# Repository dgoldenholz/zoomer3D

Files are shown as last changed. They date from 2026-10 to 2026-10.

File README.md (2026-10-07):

# Zoomer XTI-30

An articulated Blender robot based on `zoomer.png`, with a MuJoCo motor model, URDF, and print prototypes for a Prusa XL with five tools. The neutral model is 180 mm tall and 100 mm wide. The head, chest instruments, ribbed cylinder, tread base, and four-finger hands follow the drawing.

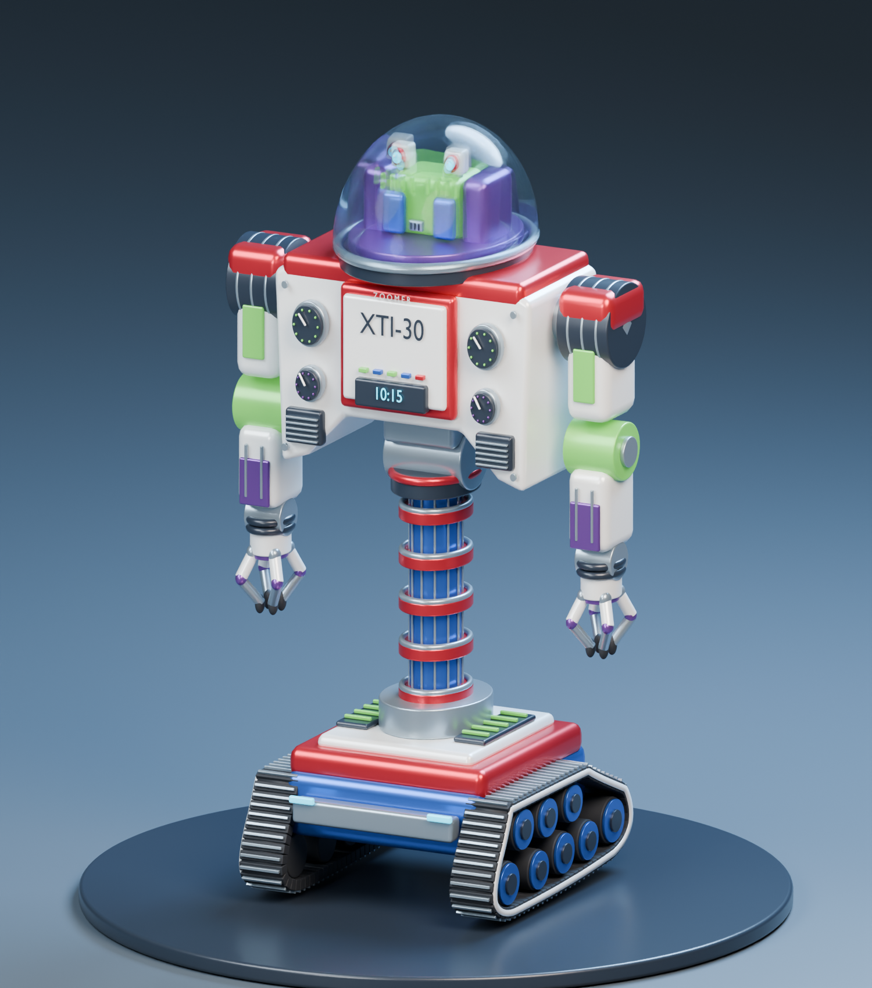
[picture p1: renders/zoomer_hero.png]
Zoomer


The revised tread layout is shown in the [side elevation](renders/zoomer_treads_side.png). The steep end is the front; the long upper slope faces rearward.

## Revised modular print

For the physical model, use [the modular print revision](print/modular/PRINTING.md). It follows the drawing's wider proportions at 180 mm tall, uses 12 printed parts and keeps only head and shoulder movement. All hardware is printed plastic. The main parts lie flat for printing; the clear dome has its own supported print.

Start with [the fit coupons](print/modular/plates/XL_fit_coupons.3mf), then choose [single-material](print/modular/plates/XL_main_single_material.3mf) or [five-color](print/modular/plates/XL_main_five_color.3mf). See the [drawing comparison](print/modular/qa/drawing_comparison.png) and [Blender inspection model](assets/zoomer_modular.blend). The files under `print/articulated/` are the earlier captive-joint prototype.

The user subsequently printed the modular robot and reported good fits, but insufficient dome clarity. The [three-piece vase dome](print/vase_dome/PRINTING.md) replaces that cover with a continuous thin shell, separate cap and mounting ring. Its two PrusaSlicer projects use 0.25 mm layers; only the shell uses vase mode. Open the [revised inspection scene](assets/zoomer_vase_dome.blend) to examine it.

The curved vase dome improved transparency in the user's print, but distorted the image. The next [flat viewing covers](print/flat_window_domes/PRINTING.md) include a flat-wall test, a faceted vase shell and a normal-printed hood that holds a 0.50 mm clear PETG sheet window. Four sliced XL projects, a full-size cutting template and both Blender inspection models are included. These new variants have not yet been physically printed.

## Drawing and training

The retrained robot completes the 19-stroke "ai is so cool" drawing with 0.36 mm RMS tracking error and returns all four markers. Open [the video player](app/video.html) or [the MP4](renders/zoomer_ai_is_so_cool.mp4). The final frame compares the target with measured ink. See [training details](simulation/TRAINING.md) for the evaluated run and simulation assumptions.

Open the local drawing studio with `.venv/bin/python app/server.py`, then visit <http://127.0.0.1:8765>. It records four-color drawings and launches curriculum training for marker collection, drawing and color changes. The default position tolerance is 3 cm RMS.

See [the workshop guide](simulation/TRAINING.md) for the simulator, learned policy, visibility checks, error calculation and commands. The [integrated articulation design](print/articulated/PRINTING.md) is separate from the original static print.

The saved PPO policy completed the four-color example in 399.42 simulated seconds, with 1.57 cm RMS error and all markers returned. This is a small controller-assisted learning test. See the workshop guide for its scope and physics assumptions.

The earlier captive mechanism is preserved in `assets/zoomer_print_in_place.blend` and `print/articulated/`. Use the modular revision above for the revised physical model.

## Open the model

Open [`assets/zoomer.blend`](assets/zoomer.blend) in Blender 4.5 or later. Frame 1 is the neutral pose. Play frames 1 to 250 for the articulation demonstration.

The `01 | Joint controls (degrees)` collection contains the joint hierarchy. Select a joint and edit its `command_deg` custom property. Clear that property's keyframes before posing it manually. Each axis has its own pivot and limit. Geometry moves as rigid parts, with no skin deformation. The dome and head rotate together through a continuous yaw joint.

The drawing is packed into the Blender file in the hidden reference collection. The studio floor, plinth, lights, and cameras are separate from the robot.

## Articulation

| Assembly | Motor channels | Motion |
| --- | ---: | --- |
| Waist | 2 | Continuous yaw; pitch ±25° |
| Head and dome | 1 | Continuous yaw |
| Each arm | 7 | Three shoulder axes, elbow flexion, forearm rotation, two wrist axes |
| Each hand | 8 | Four fingers with two hinges each |
| Base | 2 | Independent left and right drive motors |
| Total | 35 | Plus fourteen passive wheel axles |

The exact axes, ranges, torque assumptions, and ordering are in [`simulation/motor_map.json`](simulation/motor_map.json). Coordinates use metres, +X to the robot's left, -Y forward, and +Z up. The Python design file uses construction coordinates and an explicit `scale_xyz` conversion; the exported Blender, MJCF, and URDF files use metres.

## Run the simulation

```sh
python3 -m venv .venv
.venv/bin/pip install -r requirements.txt
.venv/bin/python simulation/demo.py
```

The demo follows a 10 mm circular tool path in front of a miniature whiteboard. It computes a joint target with inverse kinematics, then applies normalized torque commands at every physics step. It sets the initial joint pose once. The recorded trajectory thereafter comes from MuJoCo dynamics.

On macOS, run the interactive viewer through MuJoCo's launcher:

```sh
.venv/bin/mjpython simulation/demo.py --viewer
```

The three scenes are:

| File | Purpose |
| --- | --- |
| `simulation/zoomer.xml` | Floating base, ground contact, drive motors and arms |
| `simulation/zoomer_fixed.xml` | Fixed base for articulation and controller tests |
| `simulation/whiteboard.xml` | Fixed base, board and an attached marker representation |

[`simulation/control.py`](simulation/control.py) supplies `ZoomerEnv`. `step(action)` accepts 35 normalized torque commands in [-1, 1] and advances 10 ms. Observations include joint positions, velocities, the tool position, and a target position. The reward penalizes target distance and control effort. A tool position within 1 mm counts as success. `command(**named_torques)` provides a named interface. `simulation/zoomer.urdf` and its adjacent `meshes/` directory provide the same visual geometry and joint tree for other robotics tools.

## What the simulation establishes

The validation script loads all three scenes, runs two seconds of dynamics in each, tests all 35 motors individually, compares URDF axes and limits, and checks the circular tool trajectory. Run it with:

```sh
.venv/bin/python scripts/validate_simulation.py
```

Results are saved in [`simulation/validation.json`](simulation/validation.json). The tool trace is in [`renders/whiteboard_trace.svg`](renders/whiteboard_trace.svg), with time samples in the adjacent JSON file.

These three original scenes are controller examples. The separate workshop scene and PPO curriculum are described in `simulation/TRAINING.md`. The circle is a controller demonstration, and there is no physical ink deposition or marker-force model. The marker is attached to the palm rather than grasped as a free object. The environment is a NumPy interface, not a Gymnasium adapter. Outcome descriptions currently need numeric target positions; there is no language-to-task planner.

Masses, inertias, damping, and torque limits are design assumptions, with a total model mass of about 770 g. They are not measurements or hardware specifications. Each track follows the supplied side view: five lower wheels and three upper return rollers inside an asymmetric belt, with a steep front and a sloped rear. Wheel-contact cylinders approximate the belt contact; the first four lower contacts share the ground plane, and the rear wheel sits higher. The visible wheels have blue rims and dark hubs, with an ivory outline around the belt. The fixed-base scenes leave 2 mm beneath the tread contact cylinders so the drive motors can rotate on the bench. The belt does not circulate or deform. Robot self-collision is disabled in the starter scenes; contact with the floor and external objects is enabled. URDF uses cylinders where MJCF uses capsules. Joint sweeps can intersect the cosmetic shells, and a hardware design will need collision-aware motion limits, bearing clearances, motor mounts, wiring paths, and load checks.

## 3D printing

Start with [`print/modular/PRINTING.md`](print/modular/PRINTING.md). The older [`print/PRINTING.md`](print/PRINTING.md) describes the first prototypes. The package contains a fused static display body, a separate dome, five captive-hinge clearance variants, and a captive ball-joint prototype. The newer integrated mechanical design is in `print/articulated/`. Its captive bearings, wheels and linked treads are separate from these first prototypes.

No G-code is supplied. The older captive-joint prototypes have not been physically tested. Use their test parts to establish the printer's clearances before printing the integrated assembly.

## Rebuild

The project was generated with Blender 4.5.3 LTS and validated with MuJoCo 3.14.0. Set `BLENDER` to your Blender executable, then run. On this Mac the executable is `/Users/dgoldenh/Applications/Blender.app/Contents/MacOS/Blender`.

Blender is now 4.5.14 LTS. The modular model passed load, joint-control and render checks after the update. Automated launches on this Mac require the approved execution path outside the restricted sandbox because graphics-device detection crashed there. See the [maintenance record](diagnostics/blender/README.md) and `AGENTS.md` before rebuilding.

```sh
"$BLENDER" --background --python scripts/build_blender.py -- --render
.venv/bin/python scripts/export_simulation.py
.venv/bin/python scripts/validate_simulation.py
.venv/bin/python scripts/build_print.py
"$BLENDER" --background --python scripts/export_print_blender.py
.venv/bin/python scripts/export_display_print.py
```

The model, meshes, renders, and print files are generated artifacts. Edit `scripts/robot_design.py` to change the robot's dimensions or joint tree, then rebuild. The source drawing remains unchanged.

References used for the exports and workflow: [MuJoCo XML reference](https://mujoco.readthedocs.io/en/latest/XMLreference.html), [MuJoCo Python viewer](https://mujoco.readthedocs.io/en/stable/python.html), and [Prusa's modeling guidance](https://help.prusa3d.com/article/modeling-with-3d-printing-in-mind_164135).

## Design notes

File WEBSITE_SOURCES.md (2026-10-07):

# Zoomer3D sources

The four notebook scans and two finished-print photographs were supplied by the owner. The owner clarified that the body in the finished-print photographs is metallic silver. The owner states that the drawings were made in 1991 at age 13, and that GPT-6 Astra was used to develop the printable model and generate the printer files. On October 5, 2026, the owner confirmed that the cover shown in the photographs is the faceted printed PETG cover.

Body dimensions, joints, orientations, assembly steps and baseline settings come from `print/modular/PRINTING.md` and the embedded configurations in the XL projects. The five-color v2 project's settings differ from the baseline and are identified separately on the site.

The dome history comes from `README.md`, `print/vase_dome/PRINTING.md`, and `print/flat_window_domes/PRINTING.md`. Older notes about the faceted cover being unprinted are superseded by the owner's new photographs and confirmation. The sheet-window alternative is described as another option without a claim that it was printed.

The owner supplied `IMG_3064.JPEG` to illustrate several attempts at a more transparent head cover. It is included unchanged as `docs/assets/head-cover-attempts.jpg`.

The head-cover section uses the existing faceted-cover 3D render to identify the final design. Its numbered history ends at the faceted cover; the sheet-window design is a separate optional alternative.

The site is a static exhibit with local image and download assets. It contains no credentials or analytics. Original repository files and source photographs are preserved.

## Assembly and drawing additions

The exploded robot, cap underside and adapter views were rendered from the existing faceted-cover Blender scene on CPU. The original model files were not saved or changed. Existing cover and articulated-robot renders come from the repository.

Training metrics and programmed-versus-learned descriptions were checked against `simulation/TRAINING.md`, `training/zoomer_readable/status.json` and the recorded run metadata. The website drawing editor preserves the existing target schema and exports JSON for the local MuJoCo app. Training runs locally, not in the hosted page. The packaged MP4 is the existing 202.12-second recorded run.

The six-frame collage contains direct JPEG extractions from that packaged MP4. Captions use video playback times, not simulation time. Exact frame times and the source path are saved in `docs/assets/drawing-stills/frames.json`.

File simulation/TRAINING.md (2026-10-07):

# Drawing workshop

The workshop uses the 180 mm robot, a 480 × 200 mm whiteboard and a side table with black, red, blue and green markers. The editor maps drawings to a reachable 300 × 60 mm strip on the board. Each marker is a separate physical body.

## Open the drawing studio

From the repository root:

```sh
.venv/bin/python app/server.py
```

Open <http://127.0.0.1:8765>. Draw with a mouse, pen or touch. The editor has four colors, one 1.5 mm marker size, undo, stroke replay and JSON import/export. It saves stroke order, point order and relative timestamps. It never groups strokes by color. Black, red, black means three collection visits in that order.

Save the target, choose a training budget and select **Train this drawing**. One job runs at a time. **Stop and save checkpoint** requests a clean stop. Files stay on this computer in `targets/` and `training/<run-id>/`.

## Error and speed

The default distance tolerance is 3 cm RMS. For ordered 3D target positions `p` and measured nib positions `q`, the calculation is:

```text
MSE = mean(sum((p - q)², over x, y, z))
RMS distance = sqrt(MSE)
3 cm RMS = 0.03 m RMS = 0.0009 m² MSE
```

The UI accepts 0.05 to 10 cm. It shows both distance and MSE. The selected value is an overall error ceiling. Lettering also needs a local tracing tolerance, capped at 0.75 mm. The controller samples the path at intervals no larger than 0.6 mm and advances only after a visible, physical nib contact reaches the next point. This prevents the 3 cm default from skipping whole letters.

The reward subtracts elapsed time and control effort, and penalizes tracking errors beyond the local tolerance. Terminal evaluation also requires at least 98% of target samples to have ink within 1 mm and at least 95% of ink samples to lie within 1 mm of their assigned stroke. Missing strokes cannot earn a good score just because the completed contacts had low RMS error.

## Run or train from the terminal

```sh
# Controller baseline, with a task trace.
.venv/bin/python simulation/run_workshop.py --drawing targets/four_colors.json

# Interactive MuJoCo view on macOS.
.venv/bin/mjpython simulation/run_workshop.py --viewer

# Train the curriculum, then evaluate each stage on a separate reset seed.
.venv/bin/python simulation/train.py --drawing targets/four_colors.json --steps 100000 --output training/my_run

# Continue from a checkpoint.
.venv/bin/python simulation/train.py --drawing targets/four_colors.json --resume training/my_run/checkpoint.zip --steps 100000 --output training/continued

# Evaluate the saved policy.
.venv/bin/python simulation/run_workshop.py --policy training/my_run/policy.zip --output training/policy_trace.json
```

Stages are driving, pickup, drawing and the complete sequence. Skill resets sample different strokes and colors. A stage must pass evaluation before the next stage begins. The status file records the stage, number of training steps, measured results and whether the full sequence passed. A saved policy file alone does not mean training succeeded.

PPO learns seven residual commands around a task controller: two wheel-speed corrections, three Cartesian hand corrections, a grip correction and a head-yaw correction. Inverse kinematics and torque feedback turn those commands into the robot's 35 motor commands. This assistance shortens training. It is not learning all 35 joint torques from scratch. The zero-residual baseline is available for comparison.

The task controller preserves the drawing sequence. It carries one marker at a time, returns it to its original holder before a color change and returns the last marker when the drawing is finished. The base centers under each letter and plans an 85 mm gap to the board. Standing closer forced the wrist toward its limit and caused contact loss. For long strokes, the controller lifts the nib before repositioning along the board, then resumes the same point. Wheel residuals apply only during travel. At a station, wheel-angle feedback holds the base in place. After lifting the nib, the robot backs away with the arm held still before folding it for travel. Pickup and return can try alternate inverse-kinematics poses; writing keeps the arm configuration continuous. The ink trace records contact breaks rather than drawing a line through a pen-up move.

## Sight, contact and measurements

Both eyes have a 120° vertical field of view, with fixed optics angled 25° down. The head supplies yaw. MuJoCo rays test the field of view and occlusion by the scene and robot collision shapes. The transparent dome does not block those rays. Marker poses in the policy observation are zeroed when no sampled part of the marker is visible.

Grasping, lifting and placement require marker visibility. Drawing requires a visible patch within 3 mm of the target because the nib can cover its own contact point. An occluding wall still blocks that patch. The visibility test uses geometric object detection, not a trained RGB vision model. The task controller knows the fixed station layout. Eye cameras are present in the MJCF for future camera-based perception work.

A pickup must bring the gripper within 4 mm of the marker grip point and establish contact from at least two fingers. A weld then approximates a secure grasp. Finger-to-marker contacts are disabled while that weld holds the marker, avoiding two competing constraints. The marker can still contact the board and table. The holders use releasable docking constraints. No robot or marker pose is teleported during a task step. Curriculum resets can start near a station or with a marker already held.

Ink appears only when the nib contacts the board. Its position comes from the spherical nib's forward contact surface. A 1 kHz Cartesian feedback loop tracks the nib while torque control holds the arm pose. A slower pressure adjustment varies the normal preload between 4 and 60 mN. The nib-to-board friction coefficient is 0.2 and the grasp weld time constant is 2 ms; both are simulation assumptions. The trace retains the measured nib position, time, color, stroke index, contact flag and visibility flag. The RMS calculation includes contact samples while following the target, including samples outside the tolerance. Coverage records ordered target completion separately from error.

The drive model uses two effective traction contacts and low-friction support rollers. It is a differential-drive approximation to the treads. The decorative belt does not deform in MuJoCo. Robot self-collision remains disabled in the starter physics. Masses, inertias and torque limits are estimates. These choices support task development, but they are not a validated physical robot model.

## Validation and rebuilding

```sh
.venv/bin/python scripts/build_workshop.py
.venv/bin/python -m pytest -q tests/test_workshop.py
```

The tests cover drawing order and units, invalid inputs, eye occlusion, contact-qualified pickup, real board contact, stroke completion and invalid motor commands. `training/full_sequence.json` records the baseline's full sequence. Training results are stored separately from controller demonstrations.

The original checkpoint in `training/verified_policy/` belongs to the earlier four-mark controller. The longer target in `training/fbef1730519e4f848773550c1c03f80b/` failed during red-marker pickup and produced poorly matched lettering. Those checkpoints remain as historical artifacts. The revised controller changes the observation shape and requires a fresh policy relative to those original checkpoints. Use `--stages drawing sequence` to fine-tune these skills without repeating the pickup curriculum.

## Verified text drawing

`training/zoomer_readable/policy.zip` completes the saved 19-stroke target `targets/3201207f878b4707ab8753bffb68dbac.json`. The recorded evaluation uses seed 300 with randomized initial placement and traction. It completed all 19 strokes and returned black, red, blue and green markers in 814.74 simulated seconds.

The measured RMS tracking error was 0.361 mm, with a maximum sampled error of 0.589 mm. Every target sample had ink within 1 mm, and every ink sample was within 1 mm of its assigned stroke. The planar target-to-ink RMS distance was 0.248 mm. These figures describe this recorded run, not a benchmark on unseen drawings or hardware.

The policy accumulated 21,326 environment steps across controller revisions, including 1,024 after the canvas-to-board mapping correction. Controller changes supply most of the new capability: finer waypoint tracking, reachable drawing stances, marker-return pose recovery and contact feedback. This experiment does not isolate PPO's contribution to accuracy or speed.

The board faces +Y. Canvas-right therefore maps to world -X; canvas-up maps to +Z. Recordings retain this drawing frame alongside the target and policy hashes. The source snapshot is in `training/zoomer_readable/source/`.

Watch `renders/zoomer_ai_is_so_cool.mp4` or open `app/video.html`. Travel plays at 12x, drawing at 0.5x, and ordinary marker handling at real time. The ending compares the target with recorded contact ink. The video includes actual MuJoCo poses and does not animate the robot along the target curve.

To repeat the recorded reset with the saved policy:

```sh
.venv/bin/python scripts/record_workshop_video.py capture --drawing targets/3201207f878b4707ab8753bffb68dbac.json --policy training/zoomer_readable/policy.zip --randomize --seed 300 --output-prefix renders/repeated_text
.venv/bin/python scripts/record_workshop_video.py preview --output-prefix renders/repeated_text
.venv/bin/python scripts/record_workshop_video.py render --output-prefix renders/repeated_text
```

The implementation follows the [MuJoCo ray API](https://mujoco.readthedocs.io/en/stable/APIreference/APIfunctions.html#mj-ray), [MuJoCo weld constraints](https://mujoco.readthedocs.io/en/stable/XMLreference.html#equality-weld) and [Stable-Baselines3 PPO interface](https://stable-baselines3.readthedocs.io/en/master/modules/ppo.html).

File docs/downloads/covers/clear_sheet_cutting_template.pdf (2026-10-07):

# Zoomer clear-sheet window

## Full-size cutting template | 0.50 mm clear PETG sheet

Print at 100% or Actual size. Turn off Fit, Shrink and Scale to fit. Measure the 50 mm box below before cutting the sheet.

## Cut on the black outline

25.20 mm

37.88 mm

26.60 mm

## Narrow edge at the top

Keep the sheet flat.
Do not print this panel in filament. Leave protective film on while cutting.

Try the fit before applying adhesive. The rebate allows 0.20 mm per edge. Trim burrs rather than forcing the fit.

## Scale check

50.00 x 10.00 mm

Measure between the line centers.
If the size is wrong, correct printer scaling.

## Optional target for the flat-wall test

Place the target inside the test tube and view it through one wall only. Compare it with the uncovered target at the same distance.

# XTI-30

The tube is an optical test, not a mounting part. A flat printed wall can still show layer ripples. The sheet version removes those printed ridges.

Use with 04_XL_sheet_hood_and_retainer_NORMAL.3mf and the shared cap/adapter.
Geometry checked; this revision has not been physically printed. | 2026-10-02

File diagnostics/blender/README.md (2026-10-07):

# Blender maintenance, September 28, 2026

Blender was updated from 4.5.3 to 4.5.14 LTS, within the same release series. The active application remains at `/Users/dgoldenh/Applications/Blender.app`. The previous version is available at `/Users/dgoldenh/Applications/Blender 4.5.3 backup.app`.

The installer came from [Blender's official mirror](https://mirror.blender.org/release/Blender4.5/blender-4.5.14-macos-arm64.dmg). Its SHA-256 matched the [published checksum](https://mirror.blender.org/release/Blender4.5/blender-4.5.14.sha256). The application passed the macOS signature check and was accepted as a notarized release from Stichting Blender Foundation.

## Crash diagnosis

The crash recorded at 17:34 on September 28 occurred in `supports_barycentric_whitelist` and `MTLBackend::metal_is_supported` during Blender startup. The report had no Python backtrace. Blender had not loaded the Zoomer model or run its build script.

That launch ran inside the restricted automation environment. Subsequent launches of the same 4.5.3 binary completed outside it. This points to restricted access during graphics-device detection. It does not establish that the update alone fixes the crash.

Future automated Blender jobs use the approved execution path outside that restriction, with factory startup settings and CPU rendering. The repository's `AGENTS.md` records this requirement. Normal desktop launches continue to use the user's preferences. No macOS security settings were changed.

## Verification

The updated application launched normally on the desktop and displayed the modular model in its camera view. A separate background check opened `assets/zoomer_modular.blend`, evaluated all three joint controls at 15 degrees, restored their neutral positions and rendered the model with Cycles on CPU.

- Blender reported version 4.5.14 LTS.
- The model contained 34 mesh objects and the expected head and shoulder controls.
- The 640 by 800 pixel render completed and Blender exited with status zero.
- The saved model's SHA-256 was unchanged after the check.

The [check results](update_check.json), [render log](update_check.log) and [test image](update_render.png) record the run. This verifies startup, model loading, controls and rendering in the tested configuration. It is not a claim that Blender cannot crash under other workloads.

To roll back, quit Blender and exchange the active and backup application names in Finder. Keep the current version under another name so both remain available. The model files do not need conversion.

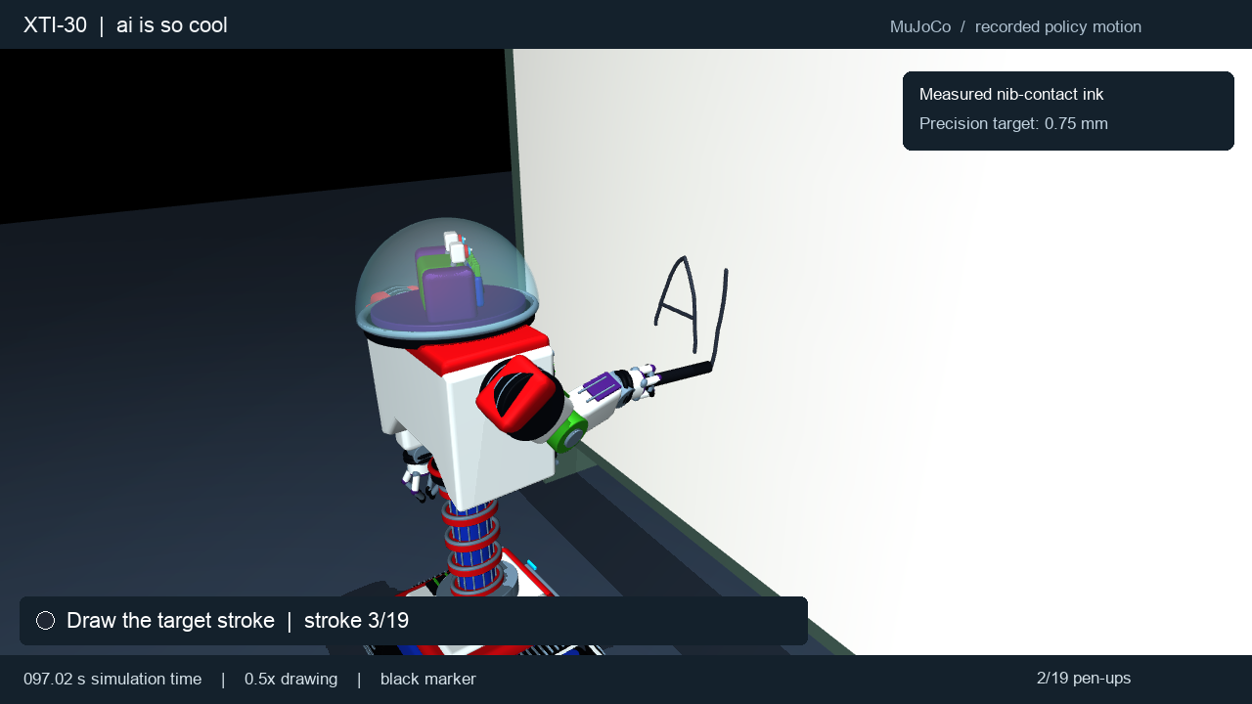
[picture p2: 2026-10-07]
docs/assets/drawing-video-poster.png

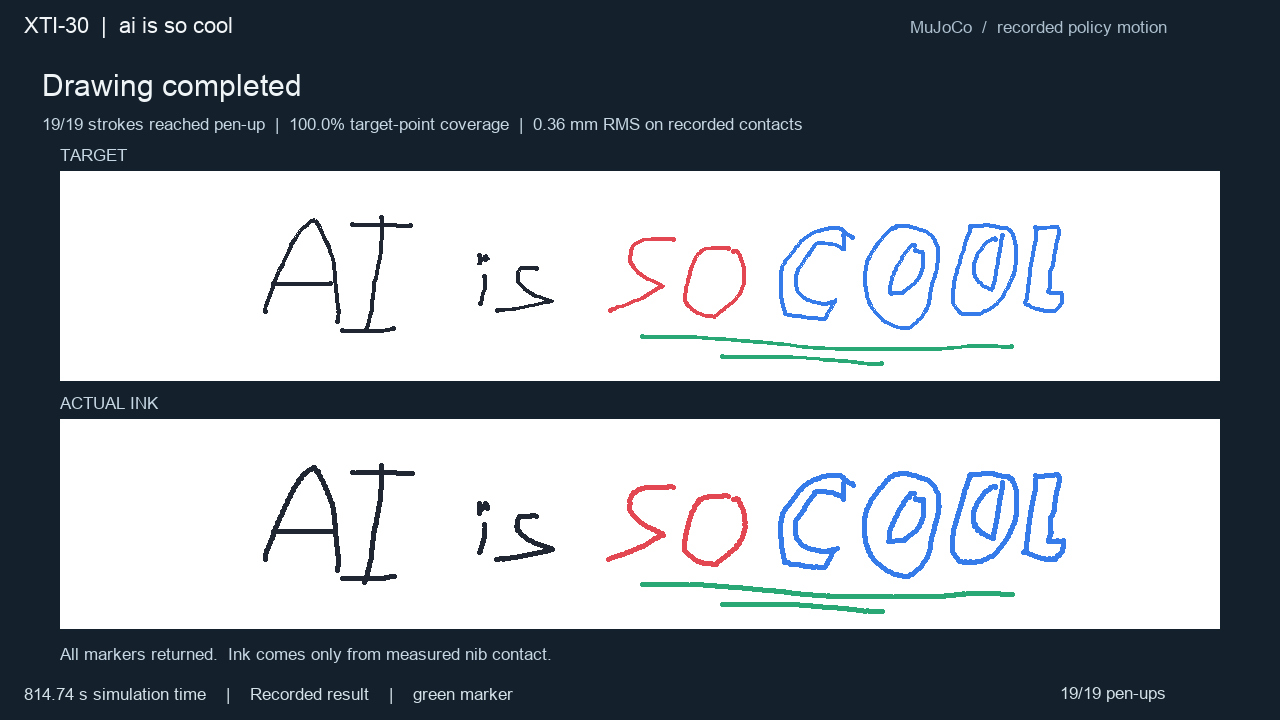
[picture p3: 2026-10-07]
renders/zoomer_ai_is_so_cool_poster.png

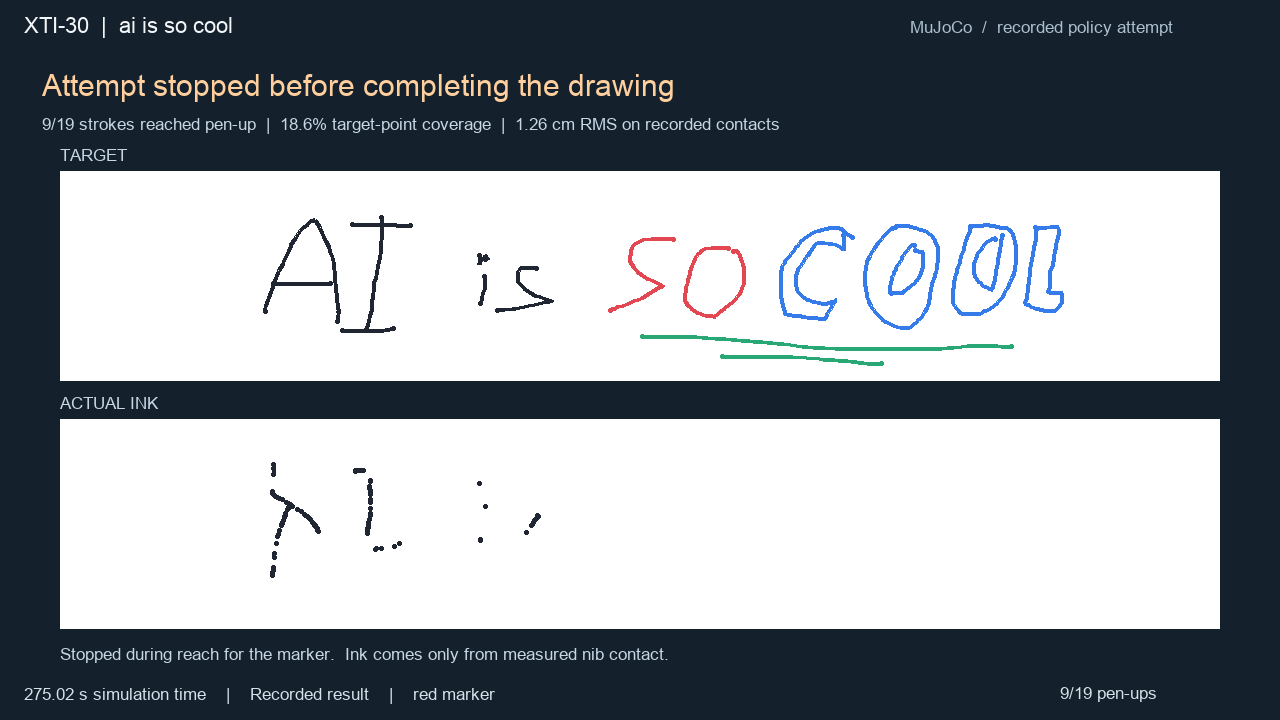
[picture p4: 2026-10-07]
renders/ai_is_so_cool_poster.png

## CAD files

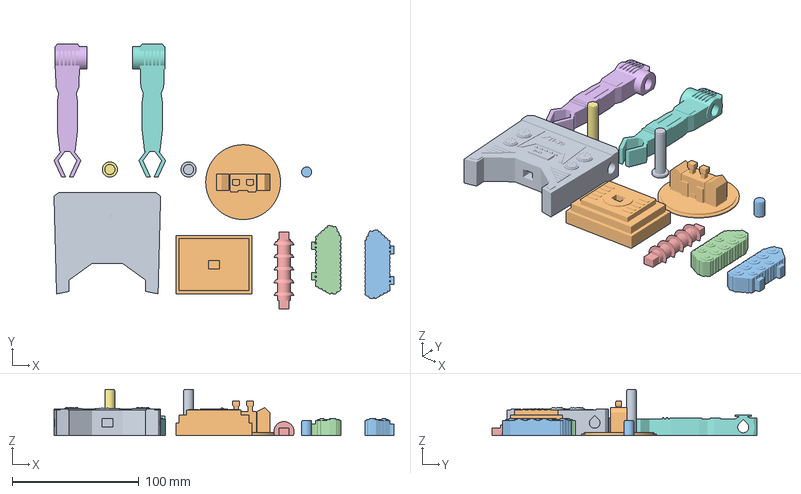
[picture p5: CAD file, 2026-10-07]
docs/downloads/body/XL_main_five_color-v2.3mf
267.8 x 209.0 x 36.3 mm
torso
base_deck
right_track
left_track
waist_column
right_arm
right_shoulder_pin
left_arm
left_shoulder_pin
head
head_peg

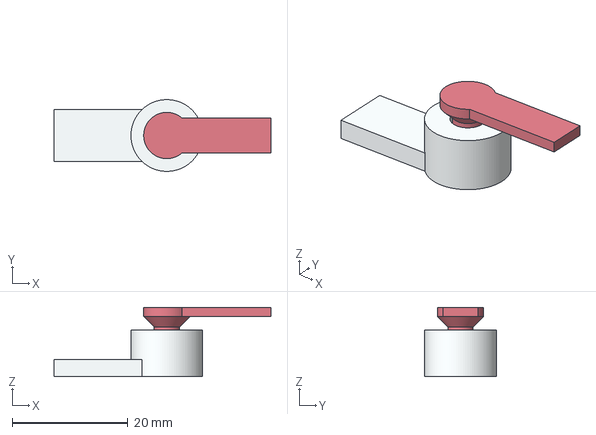
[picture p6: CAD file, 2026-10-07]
print/hinge_35_assembled.3mf
37.5 x 12.4 x 12.0 mm

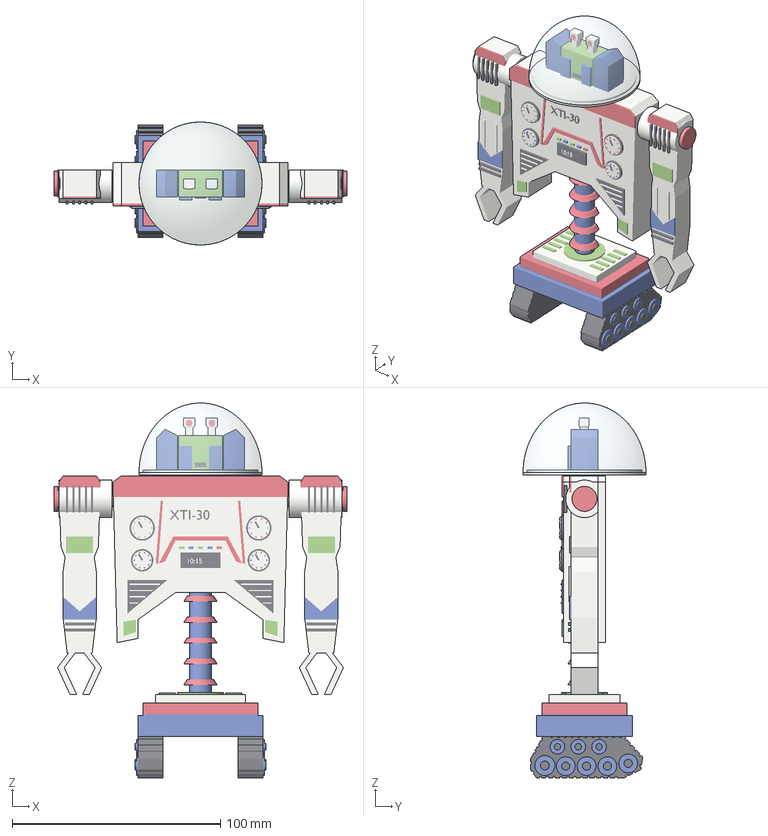
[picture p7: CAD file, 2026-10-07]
print/modular/assembly_view_only.3mf
140.6 x 59.0 x 180.0 mm
torso
base_deck
right_track
left_track
waist_column
right_arm
right_shoulder_pin
left_arm
left_shoulder_pin
head
head_peg
dome

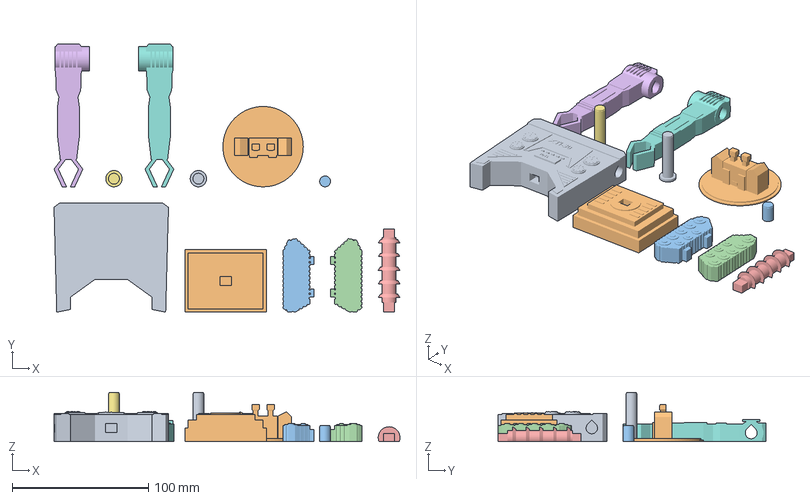
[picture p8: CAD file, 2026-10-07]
docs/downloads/body/XL_main_single_material.3mf
254.0 x 197.0 x 36.3 mm
torso
base_deck
right_track
left_track
waist_column
right_arm
right_shoulder_pin
left_arm
left_shoulder_pin
head
head_peg

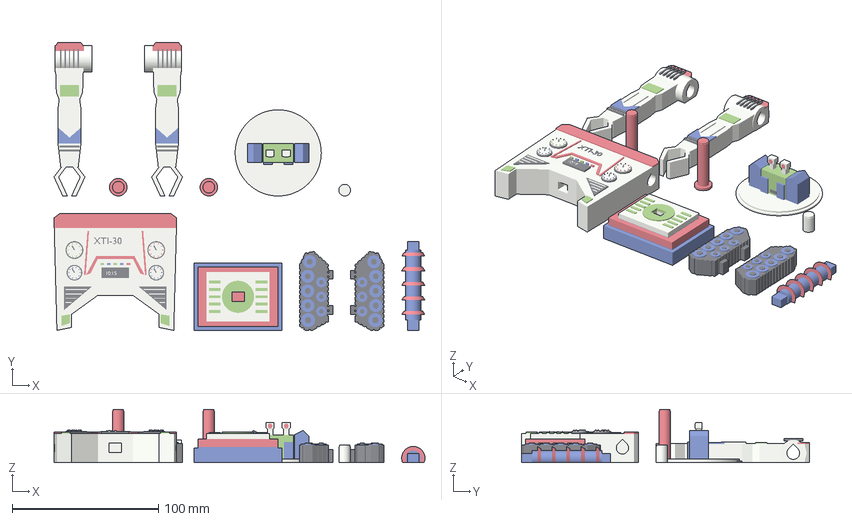
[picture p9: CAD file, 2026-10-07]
print/modular/plates/main_five_color.3mf
254.0 x 197.0 x 36.3 mm
torso
base_deck
right_track
left_track
waist_column
right_arm
right_shoulder_pin
left_arm
left_shoulder_pin
head
head_peg

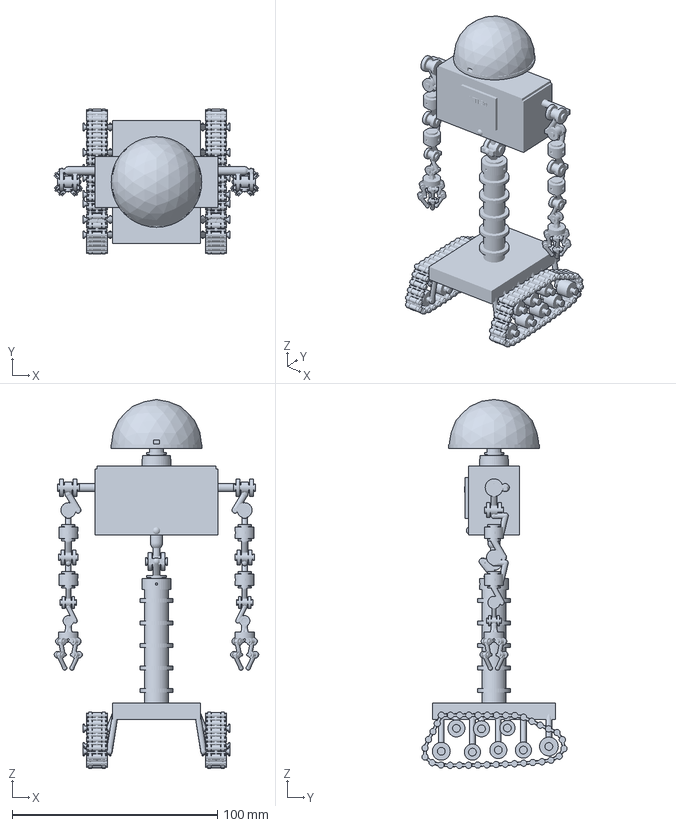
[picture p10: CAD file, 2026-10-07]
print/articulated/zoomer_prusa_XL_assembled.3mf
99.8 x 70.9 x 180.0 mm

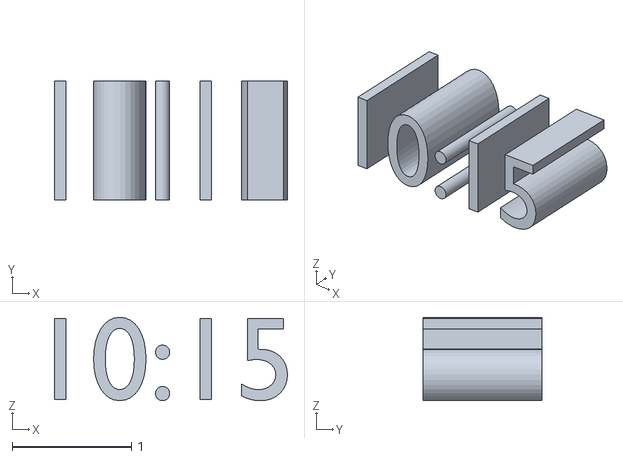
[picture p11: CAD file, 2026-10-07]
assets/modular_text/10_15.stl
1.96 x 1.00 x 0.7

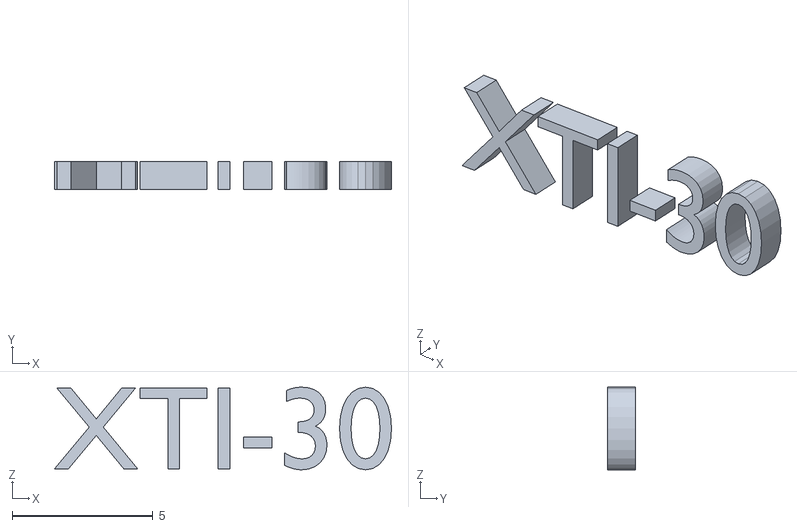
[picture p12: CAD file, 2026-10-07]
assets/print_chest_label.stl
12.0 x 1.00 x 2.94

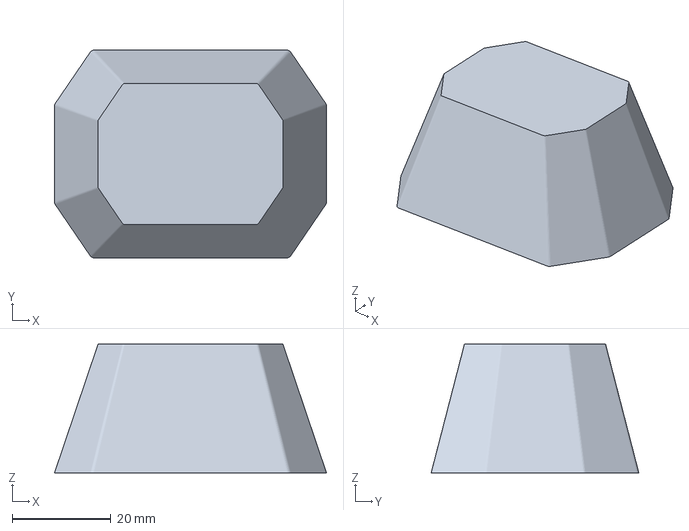
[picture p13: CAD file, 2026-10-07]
docs/downloads/covers/02_XL_faceted_shell_VASE.3mf
55.0 x 42.0 x 26.0 mm

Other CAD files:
docs/downloads/body/XL_main_five_color.3mf
print/modular/plates/XL_main_five_color.3mf
print/modular/plates/main_single_material.3mf
print/hinge_40_assembled.3mf
print/hinge_45_assembled.3mf
print/hinge_25_assembled.3mf
print/hinge_30_assembled.3mf
assets/modular_text/XTI-30.stl
assets/zoomer.blend
assets/zoomer_faceted_dome.blend
assets/zoomer_modular.blend
assets/zoomer_print_in_place.blend
assets/zoomer_sheet_window_dome.blend
docs/downloads/body/XL_fit_coupons.3mf
docs/downloads/covers/01_XL_flat_wall_test_VASE.3mf
docs/downloads/covers/01_XL_viewing_shell_VASE.3mf
docs/downloads/covers/02_XL_cap_and_ring_NORMAL.3mf
docs/downloads/covers/03_XL_shared_cap_and_adapter_NORMAL.3mf
docs/downloads/covers/04_XL_sheet_hood_and_retainer_NORMAL.3mf
docs/downloads/covers/XL_dome_PETG.3mf
docs/downloads/zoomer.blend
print/articulated/base.stl
print/articulated/dome_cover.stl
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

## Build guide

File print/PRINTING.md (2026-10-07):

# Integrated articulation update

This is an earlier prototype. Use [the revised modular XTI-30](modular/PRINTING.md) for the current print and assembly instructions.

The full passive articulation CAD is now in [articulated/PRINTING.md](articulated/PRINTING.md). The files described below remain the original static display and clearance coupons.

# Printing Zoomer on the Prusa XL

The robot's neutral dimensions are 180 mm tall by 100 mm wide, with a depth of about 72 mm. The print files use millimetres. Import them at 100% scale.

The first print should be a joint coupon. Clearances depend on material, nozzle, cooling, extrusion calibration, and orientation. The values below are starting designs, not tested settings for your machine.

## Files

| File | What it is | Status |
| --- | --- | --- |
| `zoomer_static_body_180mm.3mf` or `.stl` | Fused display body with fixed limbs and tracks | Closed mesh; supports required |
| `dome_080mm_wall.stl` | Separate open-bottom dome, about 0.8 mm wall | Closed shell mesh; test fit required |
| `clearance_coupon_plate.3mf` | Five captive hinges arranged in rows | No intersecting rotor/socket solids |
| `hinge_35_assembled.3mf` | One 0.35 mm clearance captive hinge | Suggested first coupon |
| `ball_joint_support_required.3mf` | Captive ball, stem, and socket | Internal dissolvable support required |

The display body has no moving joints. Its small decorative details are simplified during the mesh union. The dome has a plain locating rim rather than a snap fit; check the fit before applying adhesive. Do not glue the dome on if you want to keep access to the face.

## Captive hinge coupons

The five rows have radial clearances of 0.25, 0.30, 0.35, 0.40, and 0.45 mm. The row at the smallest Y coordinate is 0.25 mm; each next row is 18 mm farther along Y. Filenames encode the gap in hundredths of a millimetre. A radial gap is the separation on one side, not the total diameter difference.

Keep the rotor and socket together when importing a 3MF. They are two separate volumes in one aligned assembly. Do not auto-arrange those volumes as independent objects. The individual STL files are supplied for inspection or deliberate material assignment, not for separate placement on the bed.

Print with the hinge axis vertical. Both lower bodies start on the bed. The outer rotor arm needs accessible support underneath its overhang. Keep support out of the bearing clearance. The pin has a lower retaining flange and an upper shoulder, so it stays captive after the support under the arm is removed. Check free rotation and vertical play, then record which gap works best.

The supplied coupon rotor is 4.4 mm across the shaft, with a 7.2 mm lower flange. The socket is 12.4 mm across. These test bearings are larger than the final finger pivots would be. A successful coupon does not validate a scaled-down finger joint.

## Ball-joint coupon

The ball is 8.4 mm across, with 0.35 mm radial clearance. Its socket opening retains the ball. The ball starts above the bed inside the socket, so it needs an internal support strategy. Use a compatible dissolvable support material and confirm that fluid can reach and leave the cavity. Do not fill that trapped cavity with ordinary support material that cannot be removed through the opening.

Inspect the sliced layers before printing. Check that the ball and socket remain separate, the stem clears the opening, and support does not permanently fuse the bearing. This coupon tests retention and motion; it does not define the final two-axis waist or all the arm bearings.

## Five-tool material plan

For initial coupons, use one structural material. This separates dimensional issues from material adhesion. A second tool can carry the chosen support material.

For a later colored body, a practical five-tool assignment is ivory, red, blue, dark gray, and support. Purple and green accents can be painted or printed separately. The Blender model has more than five material roles, and the static print export does not encode a production-ready five-tool color partition.

Print the dome separately. Clear FDM filament will usually remain visibly layered; the transparent Blender material does not predict the printed optical result. A formed clear cover is another fabrication option if seeing the eyes clearly matters.

Prusa documents separate meshes for multi-material work and explains the XL's material combinations. Use those guides when choosing the final filament/support pair: [modeling for printing](https://help.prusa3d.com/article/modeling-with-3d-printing-in-mind_164135), [combining materials on the XL](https://help.prusa3d.com/article/combining-materials-xl_498103), and [tool mapping](https://help.prusa3d.com/article/tools-mapping-and-filament-mapping-xl-mmu3_732461).

## What remains before a moving full-body print

The full robot needs integrated bearing geometry, accessible support removal, structural wall thicknesses, collision clearances throughout each movement, and a print orientation for every captive component. Finger joints at this size are the hardest part. The rotating dome also needs a retaining bearing; the current separate dome is a display cover.

If physical motor actuation becomes a goal, motor choice and packaging should precede that redesign. The supplied simulated torques do not establish that 35 actuators, gearing, and wiring can fit inside a 180 mm robot.

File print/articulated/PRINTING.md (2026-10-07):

# Articulated Zoomer

This is an earlier prototype. Use [the revised modular XTI-30](../modular/PRINTING.md) for the current print and assembly instructions.

This directory contains the integrated passive articulation design. The moving parts print in their assembled positions. It has a retained waist swivel and pitch axle, a head swivel, three shoulder axes per arm, elbows, forearm swivels, two wrist axes and four two-joint fingers per hand. Both treads contain captive wheels and linked belts.

Open `zoomer_prusa_XL_assembled.3mf` in PrusaSlicer. It contains one object with named volumes and preserves the captive parts' positions. Keep the component coordinates. Do not split or arrange the moving volumes separately. The generic `zoomer_articulated_180mm.3mf` is also supplied, but PrusaSlicer can split that format into separate objects and move them to the bed. Use the Prusa-specific package for slicing. The individual STL files are for inspection and replacement exports. The Blender inspection file is `assets/zoomer_print_in_place.blend` at the project root.

This mechanism uses exposed yokes and separated joint pivots to fit printable bearings into the small robot. It differs from the cosmetic shells in the original Blender model. It is a passive poseable model. It does not contain motors, gears, wiring or a hardware control system.

The assembled CAD measures 180.00 mm tall, 99.80 mm wide and 70.87 mm deep. It contains 123 print volumes. PrusaSlicer 2.9.6 imported and re-exported the native package with one object, all volumes, all tool assignments and the same dimensions, without reporting mesh repairs. The sampled tread test found no collisions and a maximum pin misalignment of 0.0065 mm within the 0.35 mm bearing gap.

## Prusa XL setup

The design assumes 0.4 mm nozzles and 0.15 mm layers. Start with the existing captive-joint coupons before printing the whole assembly. Nominal radial and axial bearing gaps are 0.35 mm. Finger bearings use 0.30 mm. The smallest finger axles are about 1 mm in diameter and will be fragile.

Use the Prusa XL five-tool profile for the actual printer. A practical tool allocation is light PETG for the main structure, red PETG for accents, blue PETG for the base and wheels, clear PETG for the dome, and a support material whose manufacturer explicitly supports contact with that PETG. Assign all structural colors to compatible grades of PETG so joined decorative regions bond.

The Prusa-specific 3MF assigns structural volumes to tools 1–4. It does not contain a tested filament profile or printer-specific G-code. Select the five-tool XL profile, check the actual loaded materials, and assign both support and support interfaces to tool 5. The generic 3MF carries preview colors only. Clear FDM parts will be translucent unless their printing and finishing process produces optical clarity.

## Captive supports and release

Print the robot upright, with the tread bottoms on the bed. The horizontal axles, enclosed bearing gaps and suspended chain links require support. Use a compatible dissolvable material for support trapped inside captive joints. The yokes, swivel windows and dome openings provide flushing access. Breakaway support alone is unsuitable where a pin or socket encloses it.

The clear dome meets the head deck and is intended to bond to it. Both rotate together. Its openings allow internal support removal. The dome is not a separate optical lens or a removable pressure enclosure.

After support removal, free each bearing with small movements. Start with the waist and head, then the arm joints, then the fingers and tread links. Do not force a seized pin. Check the coupon results and change the parametric gap if the printer fuses a bearing. All axles have integral retaining flanges, so no separate metal pins are required for the passive model.

## What the checks establish

`validation.json` records manifold geometry, exported STL topology, neutral-pose intersections and sampled parent-child motion checks. The audit flags neutral intersections above 0.01 mm³ and motion intersections above 0.02 mm³; smaller volumes can arise from export rounding. `joints.json` gives pivots, axes, limits, nominal gaps and retaining-flange overlap. `tread_motion.json` records the sampled belt circulation check. Each joint is checked against its parent through its own range. The check does not establish clearance for every combination of whole-arm poses. These are geometric checks. They do not establish printed strength, friction, wear, support removal or the printer's achieved clearance.

No physical print has been tested. The design therefore needs coupon and first-article printing before it can be treated as a proven print-in-place mechanism. The 1 mm finger pins and the tread retaining flanges are the first features to inspect.

## Rebuild

```sh
"$BLENDER" --background --python scripts/print_label_blender.py
.venv/bin/python scripts/build_articulated_print.py
.venv/bin/python scripts/finish_articulated_print.py
.venv/bin/python scripts/check_tread_motion.py
.venv/bin/python scripts/package_prusa.py
"$BLENDER" --background --python scripts/view_articulated_blender.py
```

The final export step removes tiny triangulation features, adds the raised XTI-30 lettering and clears the moving connectors through their tested ranges. STL simplification uses tolerances no greater than 0.03 mm. Connector clearance cuts are recorded separately.

For material and support setup, follow [Prusa's XL material-combination guidance](https://help.prusa3d.com/article/combining-materials-xl_498103) and the support-filament manufacturer's compatibility instructions.

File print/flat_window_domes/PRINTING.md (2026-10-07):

	# Flat viewing covers for Zoomer

These designs follow the curved vase dome that improved transparency but distorted the view of the head. There are two replacement covers and a flat-wall test. They fit the existing modular head and use 0.25 mm layers with 0.4 mm nozzles on the Prusa XL.

The faceted cover keeps the viewing wall printable in vase mode. The sheet-window cover uses a separate piece of 0.50 mm clear PETG sheet across the face. Both use the new cap and mounting adapter in this folder. The old circular cap and ring do not fit them.

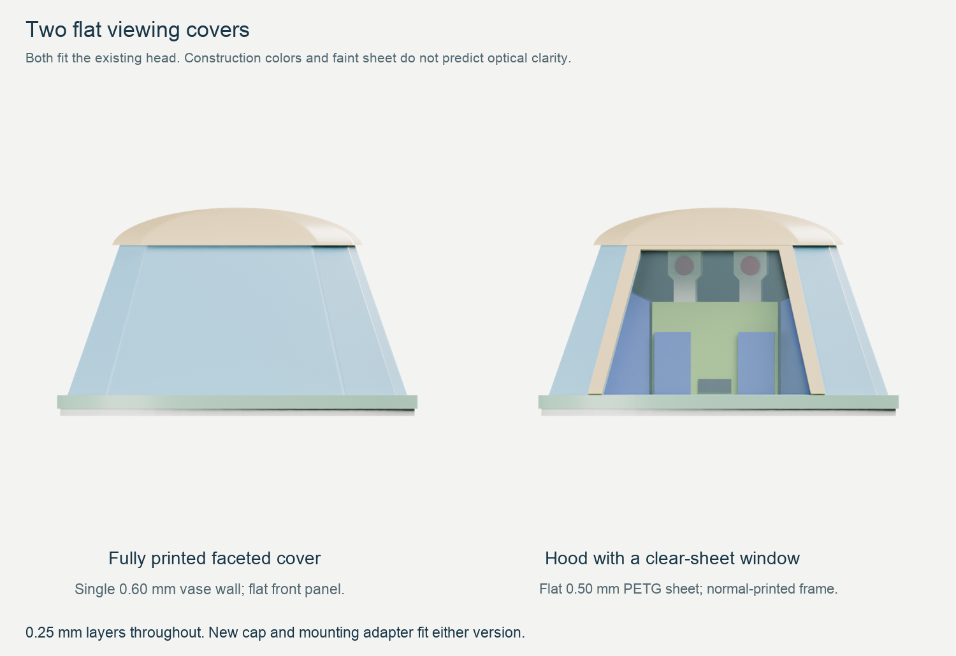
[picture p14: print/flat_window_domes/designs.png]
The two replacement covers


## Choose what to print

| Project | Purpose | Mode | Slicer estimate | PETG |
| --- | --- | --- | ---: | ---: |
| [01_XL_flat_wall_test_VASE.3mf](01_XL_flat_wall_test_VASE.3mf) | Optical test only | Vase | 16 min 17 sec | 2.55 g |
| [02_XL_faceted_shell_VASE.3mf](02_XL_faceted_shell_VASE.3mf) | Faceted viewing shell | Vase | 19 min 50 sec | 2.92 g |
| [03_XL_shared_cap_and_adapter_NORMAL.3mf](03_XL_shared_cap_and_adapter_NORMAL.3mf) | Cap and mounting adapter for either cover | Normal | 1 h 3 min 3 sec | 8.82 g |
| [04_XL_sheet_hood_and_retainer_NORMAL.3mf](04_XL_sheet_hood_and_retainer_NORMAL.3mf) | Hood and front retaining frame for the sheet version | Normal | 47 min | 4.96 g |

For the fully printed cover, print projects 02 and 03. For the sheet-window cover, print projects 03 and 04 and cut one clear sheet panel. Print project 03 twice if you want two complete covers. A loose cap can be transferred between them; each cover's adapter is normally bonded to its body.

Open each file as a PrusaSlicer project to load its embedded settings. All four use clear PETG in tool 1; the other four tools are unused. Check that tool 1 has the intended material before exporting G-code. Keep the supplied orientations and 100% scale.

## Try the flat-wall test first

The test is a 50 by 32 by 20 mm open tube with rounded corners. Its broad walls are flat. Hold the head or a printed target inside the tube and look through **one wall only**. Move the tube up or down to examine the eyes and mouth separately. The test is not a mounting part and should not be forced onto the head lip.

The [cutting-template PDF](templates/clear_sheet_cutting_template.pdf) includes a contrast target. Hold it roughly 10 to 15 mm behind one broad wall and compare it with the uncovered target at the same distance. A target placed outside the opposite side of the tube would be viewed through two walls, which gives a misleading result.

If the flat wall looks clear enough, continue with the faceted shell. If it still produces strong ripples, the sheet-window version avoids printing the optical surface. Neither new design has been physically tested.

## Print settings

| Setting | Test and faceted shell | Cap, adapter, hood and retainer |
| --- | --- | --- |
| First layer / remaining layers | 0.25 / 0.25 mm | 0.25 / 0.25 mm |
| Extrusion width | 0.60 mm | 0.45 mm |
| Perimeters | One continuous spiral | Three where space permits |
| Infill | 0% | 100% rectilinear |
| Top / bottom solid layers | 0 / 0 | 4 / 3 |
| Wall speed | 15 mm/s | 15 mm/s |
| Nozzle / bed | 250 / 85 degrees C | 250 / 85 degrees C |
| Extrusion multiplier | 1.00 | 1.00 |
| Fan range | 0 to 15% | 30 to 50% |
| Supports | Off | Off |
| Brim | 4 mm, 0.10 mm separation | Same |

These retain the settings from the previous vase experiment. Use dry filament, a PETG-compatible print sheet and a nozzle temperature within the spool's stated range. Judge geometry changes with the same material and settings first.

The two vase STLs are intentionally solid outer shapes. The slicer turns them into open, single-wall parts. Their sliced previews must show no floor, infill or roof. Do not use the thin meshes in `inspection_only/` as vase inputs, and do not combine a vase shell and fittings into one vase-mode job.

The faceted front panel leans back by 14.49 degrees but remains a plane. Its nominal width narrows from 40 to 27.2 mm; corner rounding slightly shortens the straight edges. The steepest panel moves inward only 0.085 mm per layer, leaving about 86% nominal overlap with the previous 0.60 mm extrusion. Rounded corners lie outside the main viewing area.

## Assemble the faceted cover

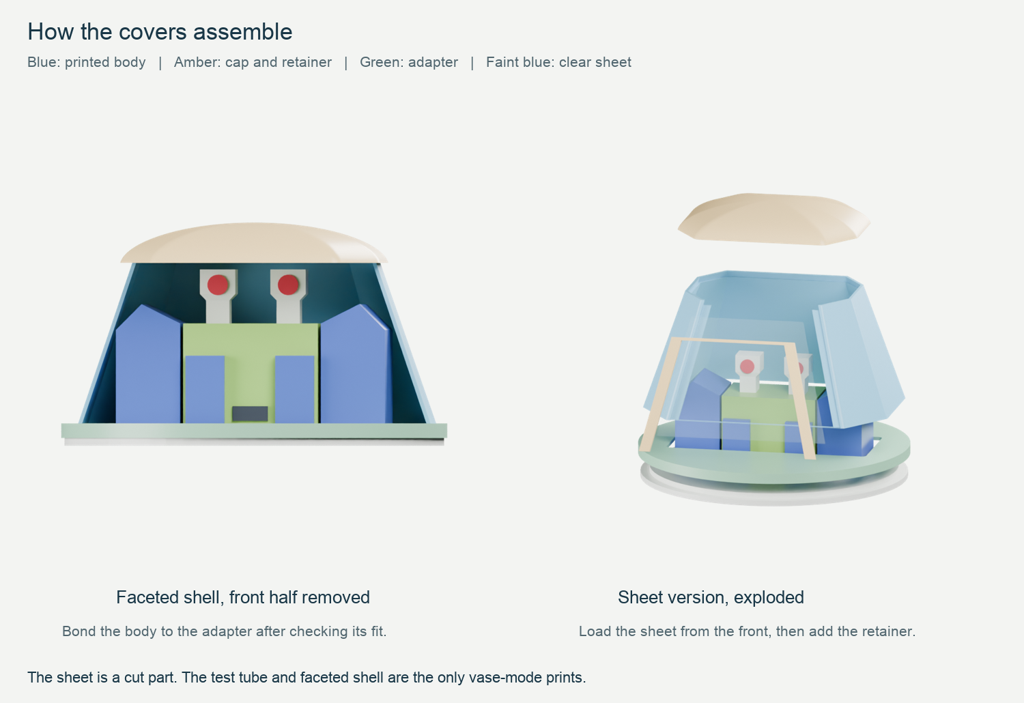
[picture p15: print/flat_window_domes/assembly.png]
Assembly views


1. Let the parts cool and remove the brim. Support the thin shell at its lower edge while trimming it.
2. Place the adapter on the head. Its circular recessed underside fits around the existing 55 mm lip. Its flat top points upward. The long direction of its rectangular opening runs across the face.
3. Center the shell on the adapter's flat top. A broad flat panel faces forward. The shell rests on the top surface; it is not a press fit into a socket.
4. Fit the cap gently to the shell's narrow upper edge. Its annular groove locates the edge. Align the broad front face of the cap with the broad front face of the shell. There is no snap latch.
5. After checking alignment, bond the shell's lower rim to the adapter with a few small adhesive dots. Keep adhesive away from the head so the complete cover can still lift off. Leave the cap removable, or secure it inside its hidden groove if needed.

Use an adhesive whose manufacturer lists compatibility with the printed plastic. Try it on an offcut first, since some adhesives haze clear PETG. Keep it out of the viewing area. These joints need no screws or metal hardware.

## Cut and assemble the sheet-window cover

Use flat, untextured **0.50 mm clear PETG sheet**, rather than a panel printed in filament. The printed hood supports the sides and back. Its front is open, with shallow ledges for the sheet. A separate U-shaped retaining frame covers the sheet's side and top edges. Its bottom stays open so it does not obscure the low mouth detail.

The panel is a trapezoid, 37.88 mm wide at the bottom, 25.20 mm at the top and 26.60 mm tall along its surface. The [full-size cutting template](templates/clear_sheet_cutting_template.pdf) provides the exact outline. A metric [SVG outline](templates/clear_sheet_outline.svg) is also included.

1. Print the PDF at 100% or Actual size, with Fit and Shrink disabled. Verify its 50 mm scale box with a ruler or calipers. Try a paper cutout in the hood before cutting the plastic.
2. Keep the sheet flat. Cut the narrow edge at the top and remove burrs. The rebate allows 0.20 mm around each edge and 0.10 mm extra depth. Do not heat or bend the sheet.
3. Set the hood on the adapter and check its orientation over the face. The supplied hood prints upright with an open top. Its last 1.25 mm reduces to a thin edge that fits the shared cap. Handle that edge gently.
4. With the cap off, place the sheet into the rebate **from the front**. It does not slide down through the narrow top. Its top edge reaches into the cap's front groove; its bottom rests just above the adapter.
5. Fit the U-shaped retainer over the front. Bond it to the solid side ledges with small adhesive dots, keeping the central sheet clear. There is about 0.10 mm between the retainer and the outer face for the bond. Remove protective film from the bonding surfaces and viewing area as appropriate.
6. Center and bond the hood to the adapter, then lower the cap onto the hood and sheet together. Check the fit before any adhesive sets. Do not push the cap down if the sheet is sitting proud; remove it and correct the sheet seating first.

The adapter prints with its broad top face on the bed, then flips over for assembly. The retainer prints flat. Those orientations are already saved in the projects. The sheet itself is not a printed part.

The cap starts 1.05 mm above the highest eye detail in the nominal assembly. Check visibility from the front when comparing covers. Looking down from above allows the opaque crown to hide more of the eyes.

## Checks and model files

PrusaSlicer 2.9.6 reopened and sliced all four saved projects without warnings. The final paths contain no supports or bridge infill. Both vase jobs have continuous rising extrusion after the first flat loop; the faceted shell has a short reposition at the first-loop transition. All six print inputs are watertight, connected solids.

The geometry check found no interference with the face or between mating parts, apart from negligible numerical contact where the adapter rests on the head. The cap retains at least 0.60 mm of material outside its receiving groove. The sheet frame's opening clears the outer eye tops and lower mouth corners when viewed from the front. Sliced shell paths leave at least 0.20 mm clearance inside the cap's ideal socket. These checks do not establish printed tolerances or optical performance.

Both covers are 33.50 mm tall above the existing head ledge, putting the full robot at about 180.1 mm. The new adapter is 60 mm in diameter, 1 mm wider than the original head deck. The head, body and joints retain their existing geometry.

The workspace inspection scenes are `assets/zoomer_faceted_dome.blend` and `assets/zoomer_sheet_window_dome.blend`. The bundle includes copies in `inspection_only/`. Their head control moves the cover with the head. The sheet is shown faintly for inspection; the renders do not predict clarity. The faceted front wall is removed only in the labeled cutaway view.

Detailed records are in [geometry.json](qa/geometry.json), [validation.json](qa/validation.json), and [the toolpath preview](qa/toolpaths.png). The build scripts are `scripts/build_flat_window_domes.py`, `scripts/validate_flat_window_domes.py`, `scripts/render_flat_window_domes.py`, `scripts/preview_flat_window_domes.py`, and `scripts/make_flat_window_template.py`. Rebuild inside the repository with its print dependencies. Follow `AGENTS.md` for Blender launches on this Mac.

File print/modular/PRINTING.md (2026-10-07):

# Modular XTI-30 for the Prusa XL

October 1 update: the user printed this robot and reported good fits. For a thinner replacement cover, use the [three-piece vase dome](../vase_dome/PRINTING.md). Its shell, cap and mounting ring replace the dome described below; the existing head and body remain usable. The replacement dome has passed slicing checks but has not been physically tested.

Use this revision for the physical model. It replaces the 123-volume captive assembly with 12 separate printed parts and three passive joints. The head turns, both shoulders swing, and the hands, waist, wheels and treads stay fixed. There is no metal hardware.

The assembled model is 180 mm tall, 140.6 mm wide and 59 mm deep. All dimensions are in millimetres. Do not rescale the project, because that also rescales its fits.

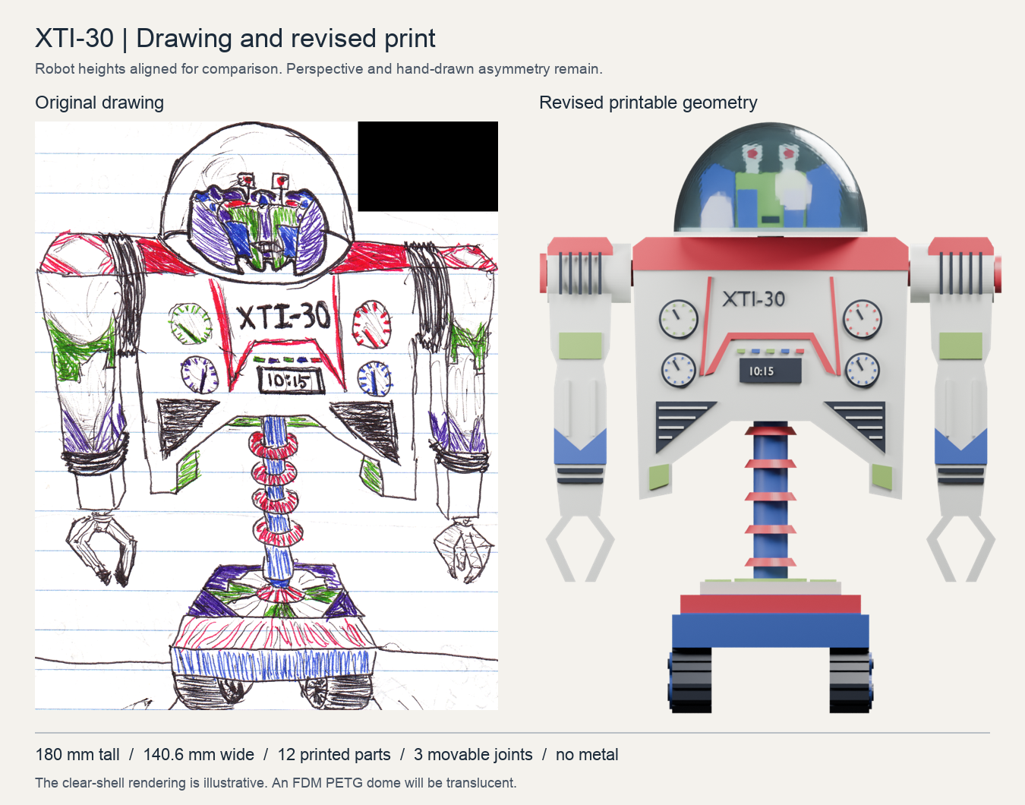
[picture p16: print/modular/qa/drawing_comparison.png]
Drawing comparison


## Files to open

1. Print [the fit coupons](plates/XL_fit_coupons.3mf) first.
2. Choose either [the single-material main plate](plates/XL_main_single_material.3mf) or [the five-color main plate](plates/XL_main_five_color.3mf). Both contain the same eleven physical parts, already oriented for printing.
3. Print [the separate clear PETG dome](plates/XL_dome_PETG.3mf) if you want the cover.

These are PrusaSlicer projects with the Original Prusa XL five-tool Input Shaper profile, five 0.4 mm nozzles, material settings and bed positions embedded. They were reopened and sliced with PrusaSlicer 2.9.6. Select the filament profile that matches the spool you actually load, and check the tool assignments before exporting your own G-code. The supplied profiles start with Prusament PLA and Prusament PETG. They are starting settings, not measurements of your filament.

The `parts/` directory contains individual STLs already in their print orientations. `assembled/` and `assembly_view_only.3mf` preserve the assembled positions for inspection. Do not print the inspection assembly upright. `../../assets/zoomer_modular.blend` contains the same exported geometry, the packed drawing, and three angle controls.

## What changed and why

| Previous failure point | Revised construction |
| --- | --- |
| Narrow body and long exposed waist | Wider shoulders, an 80 mm chest silhouette and a shorter exposed column, measured against the drawing |
| 121 captive pivots, wheel axles and tread pins | Three assembled plastic bearings |
| Roughly 1 mm finger axles and tiny retaining flanges | Fixed pincers with 3.2 mm wide rails |
| Suspended treads and wheels | Two solid track units, printed with their broad inner faces on the bed |
| Supports trapped around captive joints | Open sockets and separate pins; supports only inside the removable dome |
| Tall, fragile upright body print | Torso, arms and column lie on their rear faces |
| Horizontal column layers at the main load path | The column prints lengthwise along the bed |
| Hard-to-replace failures | Every physical part has its own STL |

Prusa recommends splitting models where this improves orientation and reduces support, and warns that fit depends on material and print direction. That is why this revision includes separate parts and matching fit coupons. [Prusa modeling guidance](https://help.prusa3d.com/article/modeling-with-3d-printing-in-mind_164135)

## Material and settings

Use PLA for the indoor display model. It is the first choice here for the lettering and gauges. Use ordinary, compatible PLA grades for all five structural colors. The raised color regions belong to each part and must bond to it. Clear PETG prints separately for the dome, so the design does not depend on PLA bonding to PETG.

| Setting | Main parts | Fit coupons | Dome |
| --- | --- | --- | --- |
| Layer height | 0.15 mm | 0.15 mm | 0.15 mm |
| First layer | 0.20 mm | 0.20 mm | 0.20 mm |
| Perimeters | 4 | 4 | 3 |
| Infill | 20% gyroid | 100% rectilinear | 0% |
| Top and bottom layers | 5 | 5 | 5 |
| Brim | 3 mm | 3 mm | 4 mm |
| Automatic support | Off | Off | On, snug, from build plate |
| Support contact gap | Not applicable | Not applicable | 0.20 mm |
| External perimeter speed | 30 mm/s | 30 mm/s | 20 mm/s |

The dome is a 1.4 mm nominal shell. Its unsupported crown needs support in this orientation. Remove that support through the full bottom opening before fitting the cover. Clear FDM PETG will usually look translucent and will show layer lines and support contact marks. The render illustrates the head through a clear shell; it does not promise optical clarity. Leaving the dome off is also a usable display option.

The five-color main plate uses tool 1 for ivory, tool 2 for red, tool 3 for blue, tool 4 for green and tool 5 for dark gray. Blue also covers the drawing's purple regions so the body fits five tools. Purple can be painted after printing. The single-material plate uses tool 1 throughout and retains all raised details for painting. The dome uses clear PETG in tool 1 on its separate plate.

On the XL, keep the active tools calibrated and their nozzle seals clean and correctly positioned. Dry filament and ooze prevention matter when tools spend time parked. The five-color project keeps a prime tower away from the parts. It uses one polymer family for the body, which avoids a tower made from materials that do not bond. If you change to mixed polymers or a different support material, recheck both adhesion and tower settings. [Prusa XL material guidance](https://help.prusa3d.com/article/combining-materials-xl_498103)

Use a clean sheet suitable for the loaded material. Smooth PEI suits PLA; satin is a practical choice for the PETG dome. Prusa warns that PETG can bond too strongly to smooth PEI and recommends a separating layer for that combination. [Prusa first-layer guidance](https://help.prusa3d.com/article/first-layer-issues_1804)

## Orientation and handling

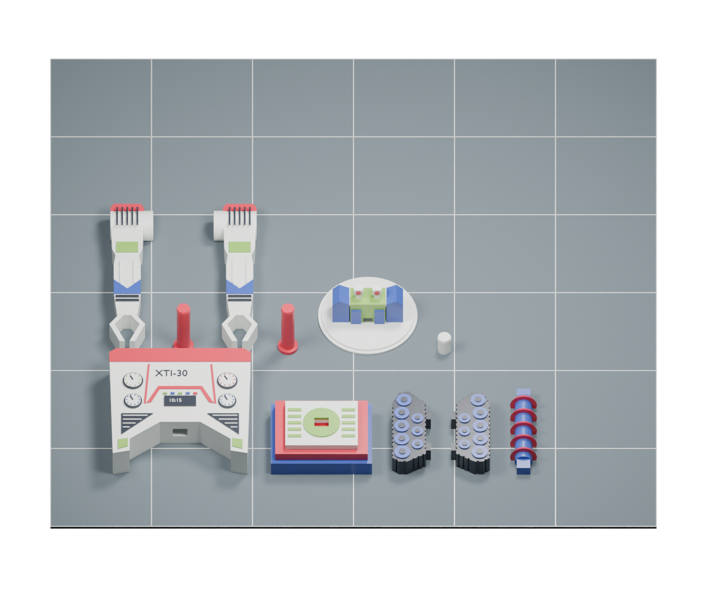
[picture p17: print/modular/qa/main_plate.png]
Main plate geometry


This view shows the saved part positions. PrusaSlicer adds the brims and, for five colors, the prime tower.

| Part | Quantity | Supplied orientation | Main concern |
| --- | ---: | --- | --- |
| Torso | 1 | Flat rear down, gauges up | Keep the raised text and dials visible in the sliced preview |
| Base deck | 1 | Underside down | Small track sockets bridge 6.6 mm across their short direction |
| Track unit | 2 | Inner face down, wheel faces up | Alignment keys now extend to the bed; remove brim from their edges |
| Waist column | 1 | Flat rear down | Keep its longitudinal print orientation; do not print upright |
| Arm with fixed hand | 2 | Flat rear down | Clean brim from the fingertips without bending them |
| Shoulder pin | 2 | Flange down | Keep the brim; do not twist a pin into a tight bore |
| Head | 1 | Deck down | Supported cheek bases and sloped socket roof remove the original overhangs |
| Head peg | 1 | Upright | Lightly deburr the tip before checking the head fit |
| Dome | 1 | Open rim down | Remove internal support before assembly |

Check the first layer across the whole plate. The XL's bed size does not make a thin, poorly attached pin reliable. The 3 mm brim addresses the pin adhesion warning found during the first slicing pass. Print the main plate by layer, as supplied. Do not enable sequential printing without checking toolhead clearance.

## Slicer estimates

These are normal-mode estimates from the saved XL projects, including their brims and the prime tower where used. Actual time depends on the printer, filament profile and any setting changes.

| Job | Estimated time | Estimated filament |
| --- | --- | --- |
| Fit coupons | 1 h 33 min | 11.8 g PLA |
| Single-material main plate | 11 h 56 min | 141.5 g PLA |
| Five-color main plate | 14 h 55 min | 165.3 g PLA |
| Separate dome | 1 h 22 min | 15.4 g PETG |

The five-color plate includes 573 tool changes and 22.0 g of prime-tower material. The single-material version is the simpler first print. The final slicing logs contain no support or stability warnings. This is a slicer result, not a guarantee of a successful physical print.

## Fit coupons

The coupons reproduce an 8 mm pin, vertical circular bores, horizontal teardrop bores, and the waist key. The three bore sizes are 8.4, 8.6 and 8.7 mm. These correspond to the torso socket, head socket and arm bearing. Their nominal radial clearances are 0.20, 0.30 and 0.35 mm. The waist key is 8 by 6 mm; its socket is 8.6 by 6.6 mm.

The round-hole bar runs from the smallest bore on the left to the largest on the right. On the long teardrop strip, the smallest bore is nearest the front of the supplied plate. Compare those holes with the printed pin. It should enter the torso socket without force and move freely in the arm and head fits. The rectangular key should enter its socket with room for a thin glue film.

Print the coupons using the same material and settings as the main parts. Remove brim and first-layer burrs before judging a fit. If a fit is tight, lightly sand the pin or key and repeat the check. If the error is large, correct the extrusion or dimensional settings and reprint the coupon. Do not scale the assembled model to correct a local fit. PETG is an alternative for the structural parts, but it needs its own coupon check and filament profiles.

## Assembly

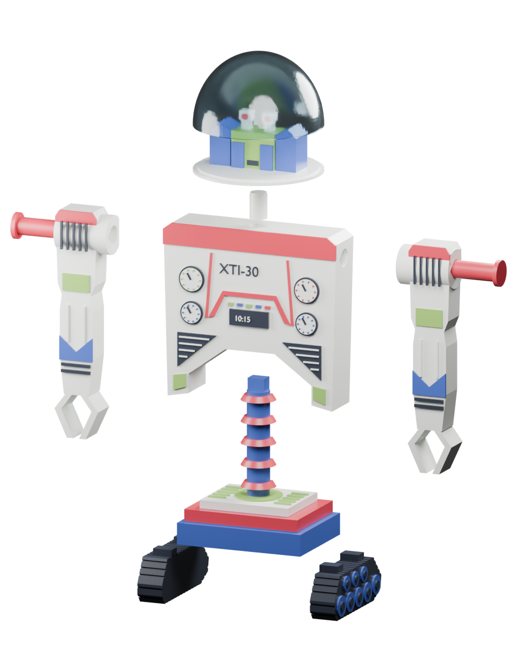
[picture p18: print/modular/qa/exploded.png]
Assembly breakdown


Use a small amount of adhesive rated for the selected plastics, following its instructions. Glue is needed for the fixed keys and pin anchors. No screws, nuts, metal rods, heat-set inserts or springs are required.

1. Dry-fit every connection. Clear the track sockets and the waist mortises. Keep the head and shoulder bearing surfaces free of glue.
2. Glue each track's two keys into the deck. The steep end of each track faces the front. Set both tread bottoms on a flat surface while the glue cures.
3. Glue the lower waist key into the deck. The flat rear of the column faces the rear of the robot. Glue the upper key into the torso, with the dials facing the same direction as the steep track ends. Support the torso until the adhesive cures.
4. Insert each shoulder pin from the outer side of the arm into the torso socket. The large flange stays outside. Glue only the innermost 5 mm of the pin. Press the flange toward light contact with the arm, then leave enough clearance for movement. A thin paper spacer can keep glue and clamping pressure out of the bearing while it cures. Do not glue the arm to the pin. The model includes axial assembly clearance; printed friction and pose holding need adjustment on the actual parts.
5. Glue the head peg into the top of the torso, leaving about 3.5 mm exposed above the chest. Keep that exposed section clean. Lower the head onto the peg and confirm it turns and lifts off.
6. Remove the dome support, clean its rim and place it on the head's outer ledge. The inner locating lip has about 0.6 mm radial clearance. The cover can remain removable. If retention is needed, use small removable adhesive dots on the ledge, away from the head bearing.

Handle the finished model by the deck or torso. The hands and eyes are details, not handles. This is a passive display model, not a powered robot or a load-bearing mechanism.

## Checks and limits

The final part meshes are watertight, each physical part is connected, and the assembled solids have no intersections above the 0.005 mm³ audit threshold. All colored export meshes are also watertight. The checks sample each shoulder from -75 to +75 degrees in 5-degree steps and the head through a full turn in 10-degree steps. None of the 99 sampled poses intersects the stationary assembly.

PrusaSlicer completed the four supplied projects using the embedded XL settings. The main plates and coupons use no support toolpaths. The dome has support enabled and generated. See [the validation record](qa/validation.json), [mesh checks](qa/geometry.json), and the adjacent slicing logs for the exact result and estimates. These checks do not measure layer adhesion, joint wear, printed friction, material shrinkage, optical clarity or actual strength. No physical print has been performed.

## Rebuild

Use a Python environment with the packages in `requirements-print.txt` at the repository root. Blender generates the lettering and inspection renders. The build scripts operate only on this modular print revision.

```sh
python scripts/build_modular_print.py
python scripts/package_modular_print.py
```

The packaging script uses the installed PrusaSlicer application on this Mac. To regenerate lettering first, run Blender with `scripts/modular_text_blender.py`. To rebuild the inspection scene and images, run it with `scripts/render_modular_blender.py`. After slicing the four native projects, `scripts/validate_modular_print.py` checks the exported parts, motion and G-code settings. The source drawing and the trained simulation remain separate.

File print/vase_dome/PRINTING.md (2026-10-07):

# Vase dome for the existing Zoomer head

Follow-up: the user printed this version and reported improved transparency with lens-like distortion. The [flat viewing alternatives](../flat_window_domes/PRINTING.md) address that result with a faceted shell and a separate clear-sheet window. The original checks below describe the state before that print.

This cover replaces the cloudy dome with three printed parts: a thin viewing shell, a crown cap and a mounting ring. It fits the existing modular head. All connections use plastic; no metal hardware is needed.

The user confirmed that the earlier robot print fit well. This replacement has passed mesh, fit-envelope and PrusaSlicer checks, but has not been physically printed. Its thinner wall may improve visibility; the clarity of the Overture PETG still needs a print test.

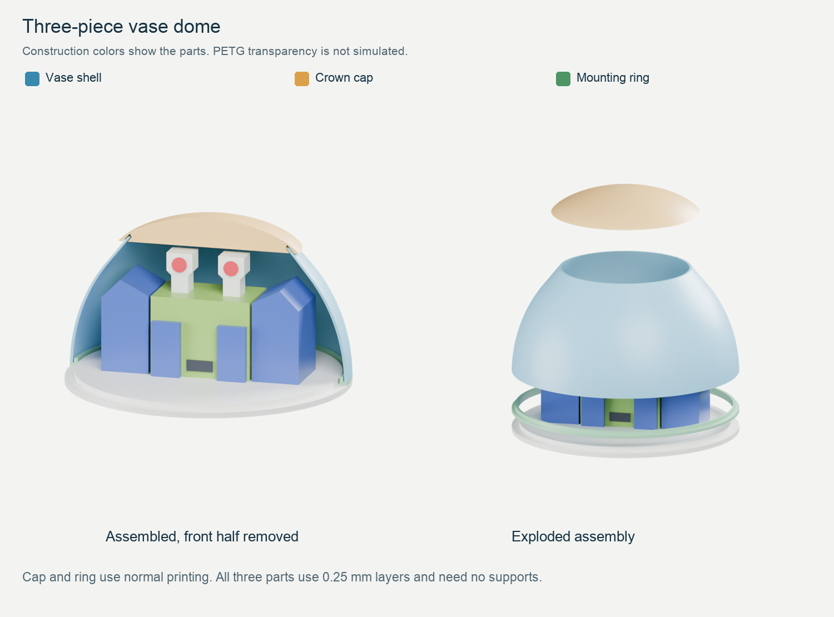
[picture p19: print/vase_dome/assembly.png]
Assembly and cutaway


## Open these two projects

| PrusaSlicer project | Parts | Mode | Estimated time | PETG |
| --- | --- | --- | ---: | ---: |
| [01_XL_viewing_shell_VASE.3mf](01_XL_viewing_shell_VASE.3mf) | Viewing shell | Spiral vase | 22 min 16 sec | 3.37 g |
| [02_XL_cap_and_ring_NORMAL.3mf](02_XL_cap_and_ring_NORMAL.3mf) | Crown cap and mounting ring | Normal | 42 min 9 sec | 5.84 g |

Open each as a **project** so PrusaSlicer loads its settings. Both use the XL five-tool Input Shaper printer profile with 0.4 mm nozzles, clear PETG in tool 1, and 0.25 mm layers including the first layer. The other tools are unused. Keep the parts at 100% scale and in their supplied orientations. Export G-code for your printer after checking the preview.

Print the shell first and hold it over the face to judge visibility before spending time on the fittings. Let the bed cool before removing it, and support the lower rim while trimming its brim.

The vase STL is deliberately a **solid outer shape**. After slicing, its toolpath must be one wall with an open bottom and open top. Printing that STL with an ordinary profile would create the wrong part. Prusa recommends a solid input for vase mode; the slicer creates the thin wall. [Prusa vase-mode documentation](https://help.prusa3d.com/article/layers-and-perimeters_1748)

Only the viewing shell uses vase mode. The cap's receiving groove and the ring's locating sleeve require normal printing. Combining all three into one vase job would destroy those features.

## Supplied settings

| Setting | Viewing shell | Cap and mounting ring |
| --- | --- | --- |
| Layer height / first layer | 0.25 / 0.25 mm | 0.25 / 0.25 mm |
| Extrusion width | 0.60 mm | 0.45 mm |
| Perimeters | 1, continuous spiral | 3 |
| Infill | 0% | 100% rectilinear |
| Top / bottom solid layers | 0 / 0 | 4 / 3 |
| Wall speed | 15 mm/s | 15 mm/s |
| Solid infill speed | Unused | 20 mm/s |
| Nozzle / bed | 250 / 85 °C | 250 / 85 °C |
| Extrusion multiplier | 1.00 | 1.00 |
| Fan range | 0–15% | 30–50% |
| Brim | 4 mm outer, 0.10 mm separation | Same |
| Supports | Off | Off |

These temperatures and cooling values are trial settings for clear PETG, not a measured calibration of your spool. Check the temperature range on its label. Use dry filament and a PETG-compatible sheet; retain any separating-layer practice required by your sheet. Avoid increasing flow and temperature together, because that makes fit and clarity changes harder to diagnose.

The shell uses a wider single extrusion to keep adjacent loops overlapping as the dome narrows. At its steepest section, each 0.25 mm rise moves inward by 0.20 mm, leaving about two-thirds nominal overlap. The 0.60 mm horizontal wall is about 0.47 mm thick normal to that slope. A separate cap closes the crown, where a continuous unsupported spiral would become unreliable.

Slow printing and reduced cooling are consistent with Overture's transparency guidance. This version keeps the requested 0.25 mm layers and existing 0.4 mm nozzle. It does not establish that those settings will make the face sufficiently visible. [Overture PETG guidance](https://overture3d.com/en-gb/blogs/blogs/petg-filament-guide-3d)

## Orientation and assembly

1. **Print the shell with its large opening on the bed.** The smaller opening stays open. Do not add a bottom, top layers or supports. The first loop and brim are flat; the wall then rises continuously. PrusaSlicer adds a finishing loop at the top.
2. **Print the cap with its groove facing the bed**, as supplied. Its center disk and outer rim initially print as separate regions, then join through a tapered groove roof. Leave it attached to the bed until printing finishes. The final slice has no bridge infill or supports.
3. **Print the ring with its broad flange on the bed.** Its raised sleeve points upward. Remove brim and any first-layer burrs from the fittings before assembly.
4. **Place the ring over the existing head lip.** Its 55.8 mm opening fits around the 55.0 mm lip. It rests on the existing head ledge. The ring is a slip fit, so it will lift off with the cover if the cover and ring are bonded together.
5. **Seat the shell on the ring's ledge.** The ring's raised sleeve goes inside the shell. Hold the shell by its lower rim, without squeezing the sides. If retention is needed, use a few tiny dots of a clear adhesive whose manufacturer lists compatibility with PETG, confined to the hidden base joint. Test it on scrap first; adhesive can haze the viewing area.
6. **Lower the cap onto the shell's upper edge.** The edge enters the annular groove. This is a loose locating fit, not a snap fit. Stop when it seats gently; do not press it down. Leave it removable, or secure it with small adhesive dots inside the hidden groove if needed. Keep the ring free of the head if you want to remove the whole cover later.

The cap starts nominally 1.05 mm above the highest eye detail. Allowing for up to 0.25 mm of seating movement leaves 0.80 mm. The thicker crown therefore stays above the eyes when viewed straight ahead, though it will obscure more of them from above.

If a fit is tight, remove burrs from the rigid cap or ring and try again. Do not force or sand the thin viewing wall. If the shell has gaps, bubbles or loose loops, resolve that print defect before judging optical clarity or applying adhesive.

## Shape and fit

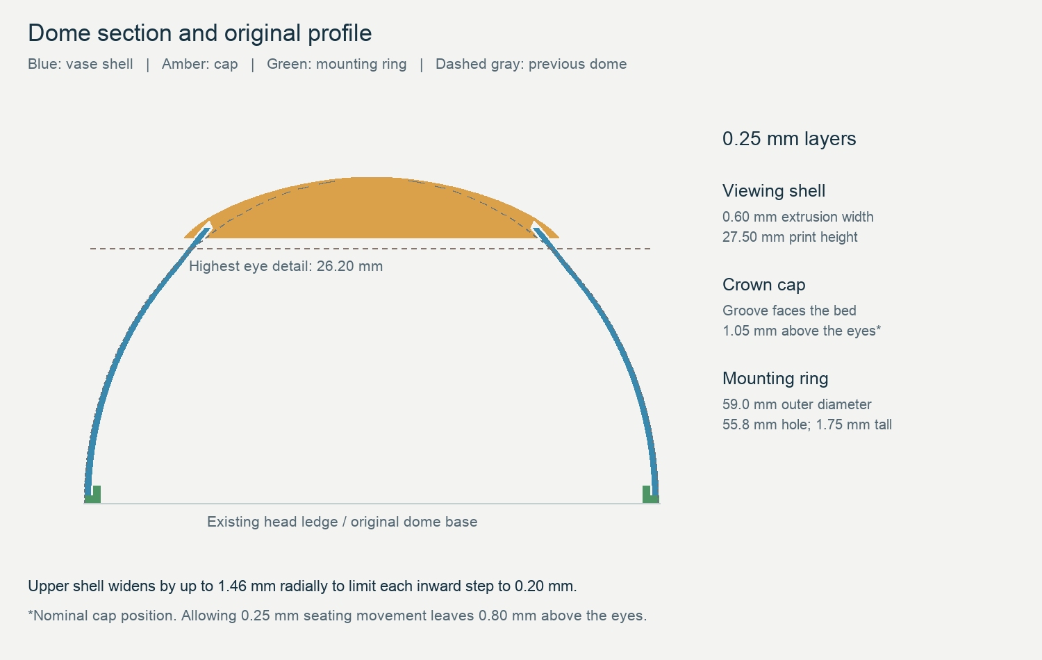
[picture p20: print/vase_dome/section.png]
Section through the replacement cover


The base remains 59 mm wide. The lower shell follows the previous dome profile; the upper shell widens by up to 1.46 mm radially to reduce the unsupported inward step. The cap has a small overhanging rim to hold its groove and extends up to 2.58 mm radially beyond the previous crown profile. Nominal assembled height is 33.50 mm, versus 33.40 mm for the previous dome, putting the full robot at about 180.1 mm. The body, face and joints retain their existing geometry.

The cap groove is 1.10 mm wide around a nominal 0.60 mm wall. Nominal radial clearance is 0.25 mm on each side. Measured shell toolpaths reduce the smallest outer clearance to about 0.15 mm. The mounting ring has about 0.22 mm minimum radial clearance inside the shell and 0.40 mm around the head lip. These are geometric checks, not a tolerance guarantee for a physical print.

## Validation and files

PrusaSlicer 2.9.6 reopened and sliced both saved projects without warnings. All three STL inputs are watertight and each contains one connected part. The shell's toolpaths rise continuously, contain no infill or support, and stay at or below 15 mm/s. The tapered cap groove closes without bridge infill. Checks found no interfering fit volumes, apart from negligible numerical contact at the ring's resting surface. [Validation results](qa/validation.json) and [geometry measurements](qa/geometry.json) record the details.

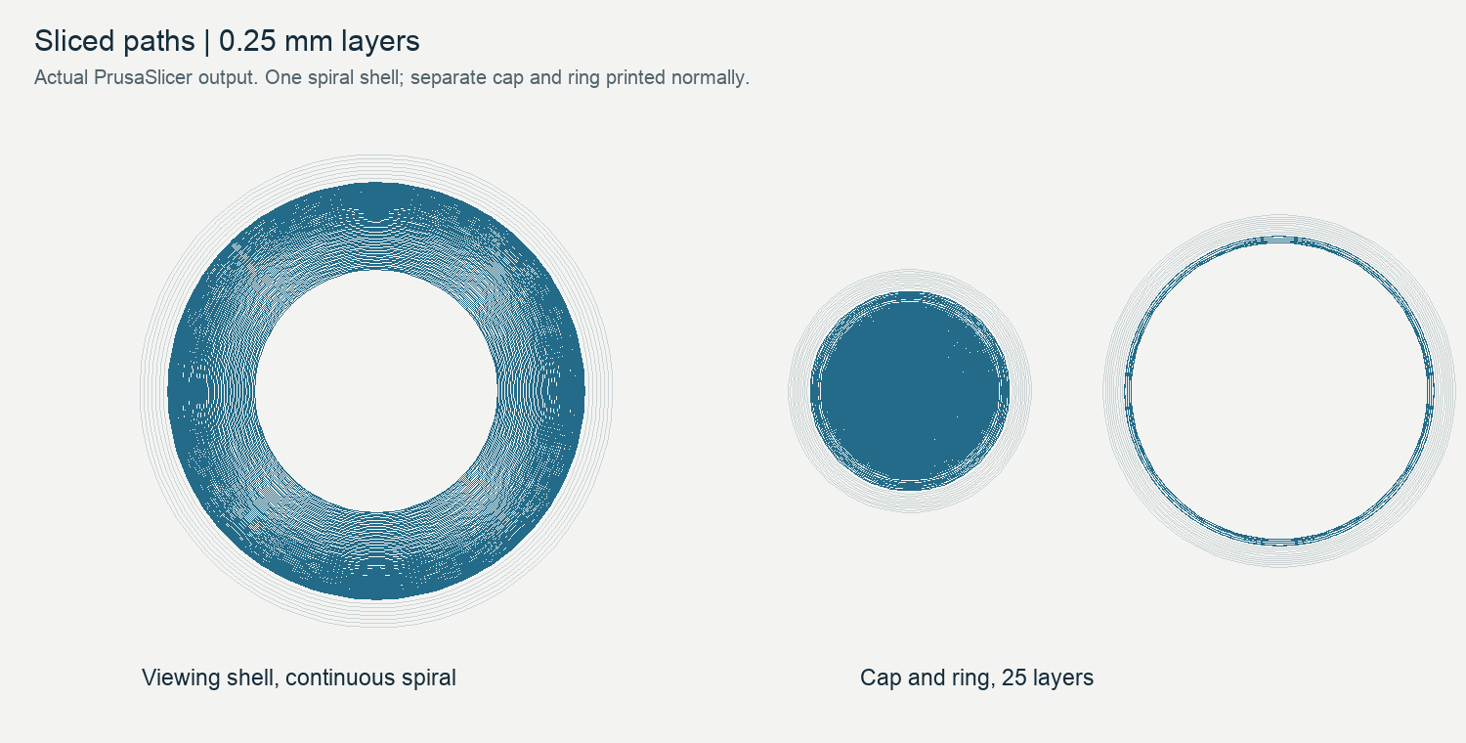
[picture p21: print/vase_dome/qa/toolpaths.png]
Actual sliced toolpaths


The three files in `parts/` are print inputs. The meshes in `inspection_only/` show the parts in assembled positions, including an approximation of the actual thin wall. **Do not use the inspection shell as the vase input.** The bundle includes `inspection_only/zoomer_vase_dome.blend`; the workspace copy is `../../assets/zoomer_vase_dome.blend`. Its head control moves the cover with the head. Construction colors identify the parts and do not simulate PETG clarity.

Rebuild geometry and projects with `scripts/build_vase_dome.py` using the repository's print dependencies. Slice each project to G-code, then run `scripts/validate_vase_dome.py`; it reads `/private/tmp/zoomer_vase_window.gcode` and `/private/tmp/zoomer_vase_fittings.gcode`. Rendering uses `scripts/render_vase_dome.py` with the original modular Blender scene as input and the approved launch procedure in `AGENTS.md`. `scripts/preview_vase_dome.py` creates the assembly card and section. Existing print projects and the original Blender model remain available.

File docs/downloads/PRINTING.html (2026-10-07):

# Zoomer3D printing and assembly guide

The finished robot uses the faceted printed PETG cover.

03 / The part that took a few tries

## A clear head wasn't so simple.

The original dome was not transparent enough to see the head properly. Getting a cover clear enough for the character took several iterations.

A thinner curved shell let more light through, but distorted the face like a lens. The faceted printed PETG cover finally gave a clear enough view of the head. That's the version in the photos.

See the cover files

1. 01

### The original dome

  A supported PETG shell with a nominal 1.4 mm wall. It fit, but the print was too cloudy.
2. 02

### A thinner curved shell

  One continuous vase-mode wall, with a separate cap and mounting ring. Transparency improved; the curved wall still distorted the view.
3. 03

### The successful faceted cover

  A small flat-wall test led to a faceted vase-mode cover. Its broad front panel removes the curve from the main viewing area. This is the cover on the finished robot.
4. 04

### Another option, a sheet window

  A printed hood can also hold a flat 0.50 mm PETG sheet. The viewing window is cut from clear sheet rather than printed in layers. This alternative is not the cover in the photos.

04 / Make your own

## Print a Zoomer.

The supplied projects are set up for the Original Prusa XL with five tools and 0.4 mm nozzles. Open each 3MF as a project to load its settings, then slice for the printer and filament you use.

Keep the files at 100% scale and in their saved orientations. The robot is about 180 mm tall, 140.6 mm wide and 59 mm deep. Scaling also changes the joint clearances.

### How the printed parts go together

Dry-fit the connections before using adhesive. This exploded view includes the newer faceted cover.

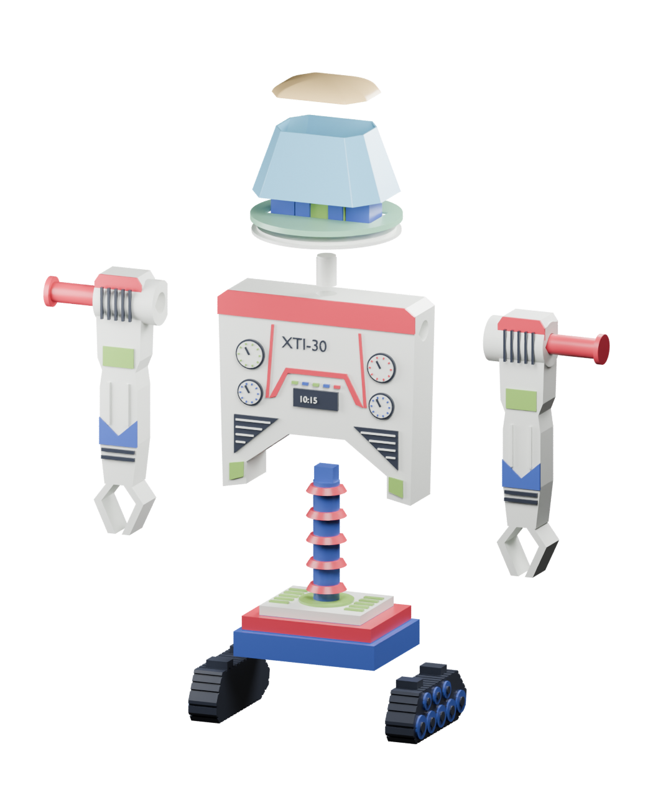
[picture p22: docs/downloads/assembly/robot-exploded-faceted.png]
Exploded 3D view of the printed robot, with tracks below the deck, the waist below the torso, arms and pins at the sides, and the head and faceted cover above.


The parts are separated to show their connections. Select the image for a larger view.

1. 1

#### Tracks into the deck

  Glue the two keys on each track into the underside of the deck. The steep track ends face forward. Rest both tracks on a flat surface while the glue cures.
2. 2

#### Column between deck and torso

  Glue the column's lower key into the deck and its upper key into the torso. Its flat side faces the back. Support the torso until the adhesive cures.
3. 3

#### Shoulder pins through the arms

  Insert each pin from outside the arm, with its flange staying outside. Glue only the innermost 5 mm into the torso socket. Leave the arm free to swing.
4. 4

#### Head onto the peg

  Glue the peg into the torso with about 3.5 mm exposed. Leave that exposed section clean. Lower the head onto it and check that it turns and lifts off.
5. 5

#### Add the faceted cover

  The adapter sits on the head, the thin shell rests on the adapter, and the cap closes the top. Use the close-ups below to check each connection.

### Build the faceted head cover

Blue identifies the thin shell, amber the cap, and green the adapter in these construction renders. All three parts print in clear PETG. These views explain the geometry rather than predict its transparency.

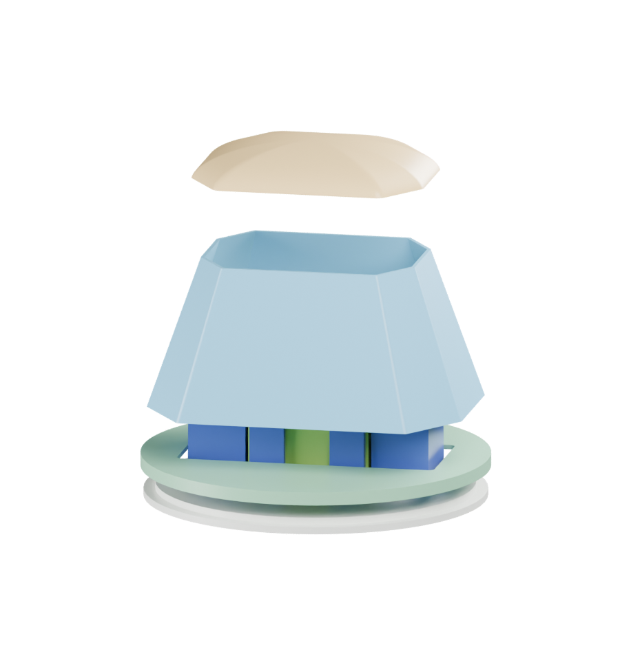
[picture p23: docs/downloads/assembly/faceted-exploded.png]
Exploded head cover showing the cap lifted above the faceted shell and the adapter around the head below it.


Top to bottom: cap, faceted shell, adapter, existing head deck.

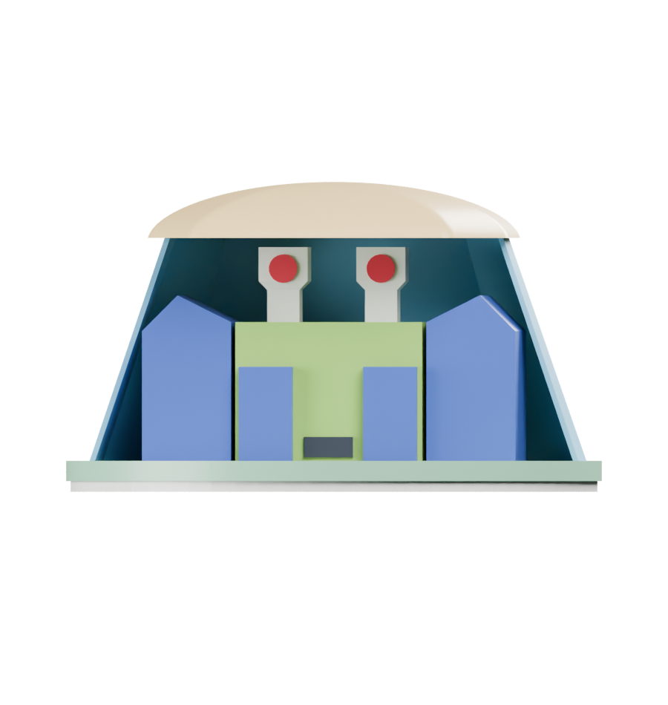
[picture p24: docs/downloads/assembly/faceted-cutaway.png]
A front cutaway of the faceted cover showing the head below the cap and the shell resting on the green adapter.


Front half removed for this cutaway. The complete printed shell surrounds the head.

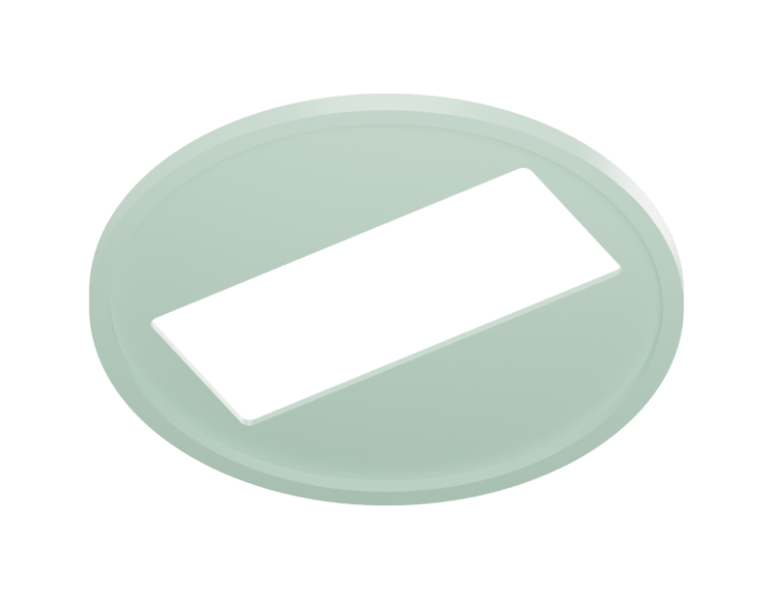
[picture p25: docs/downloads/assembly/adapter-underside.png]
Underside of the green lower adapter, showing the circular recess that fits around the head lip.


#### 1. Bottom section onto the head

The circular recess faces down and fits around the existing 55 mm head lip. The long opening runs across the face. Keep this connection free of glue if you want the cover to lift off.

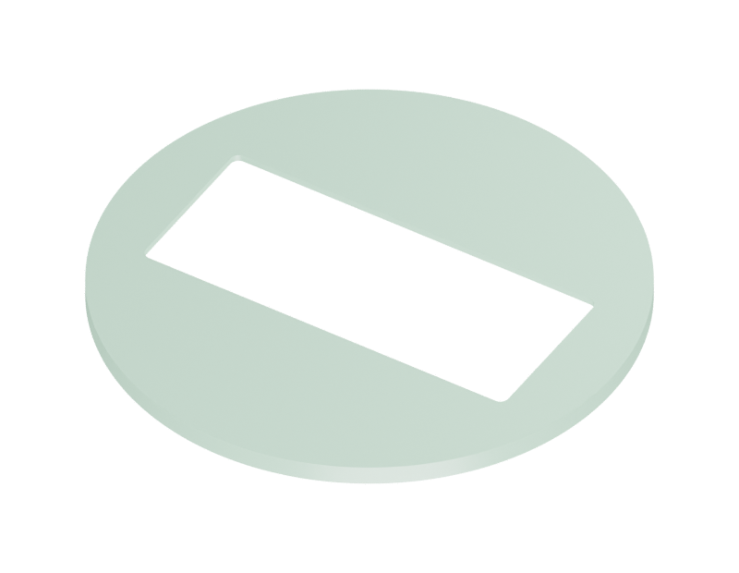
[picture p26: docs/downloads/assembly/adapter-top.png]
Upper face of the lower adapter, with a flat ledge around the rectangular opening for the shell to rest on.


#### 2. Shell onto the flat ledge

The adapter's flat face points up. Center the shell on it with a broad flat panel facing forward. It rests on the surface rather than pressing into a socket. Bond only the hidden lower rim with small adhesive dots.

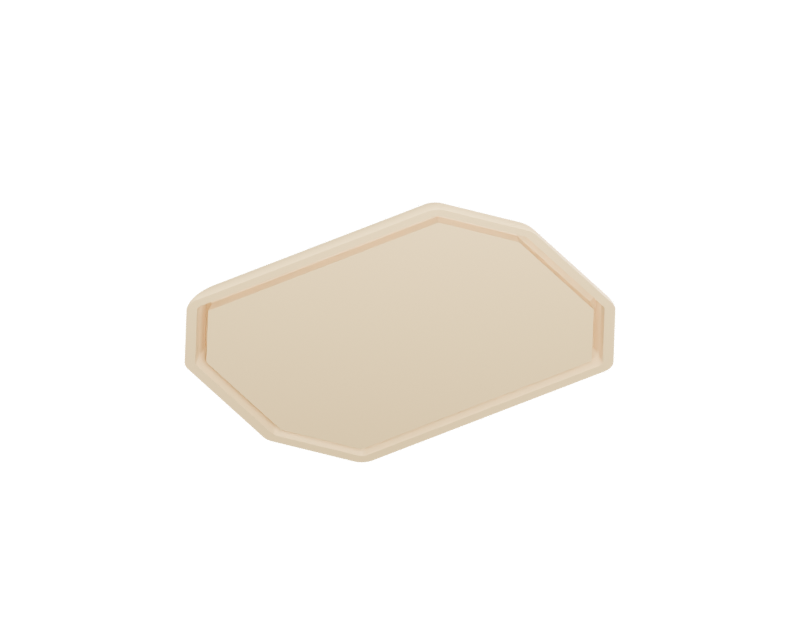
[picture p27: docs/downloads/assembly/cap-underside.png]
Underside of the upper cap, showing the continuous groove that receives the shell's narrow upper edge.


#### 3. Top section onto the shell

Lower the cap's groove onto the shell's narrow upper edge. Align the broad front faces. This is a gentle locating fit, with no snap latch. Leave the cap removable or secure it inside the hidden groove.

Let parts cool, remove brims and deburr the rigid fittings. Hold the thin shell at its lower rim. Test PETG-compatible adhesive on scrap and keep it away from the viewing panel.

1. 01

### Check the fits first.

  Print the fit coupons in the same PLA and with the same settings as the body. Remove the brim and first-layer burrs. The pins should enter without force, and the head and shoulder bearings should move freely. Lightly deburr a tight pin; correct a large dimensional error before printing the body.
  Fit coupons 3MF
2. 02

### Print the eleven body parts.

  Choose the five-color plate, or print the single-material plate and paint the raised details. Both contain the same eleven parts. Use compatible PLA for the body and keep the supplied orientations. The torso, arms and waist column lie flat; the track units print with their inner faces down.
  1 Metallic silver2 Red3 Blue4 Green5 Dark gray
  To match the photos, load metallic silver in tool 1. The supplied project still labels these parts "ivory" and uses an ivory preview color. Select the profile for your silver filament before slicing.
  Blue takes the place of purple in the drawing to keep the print to five tools. Check loaded colors and filament profiles before slicing.
  Five-color body 3MFSingle-material body 3MF
3. 03

### Print the cover separately.

  Use dry clear PETG in tool 1. Start with the flat-wall test and judge the head through one wall. For the faceted printed cover, print the shell in vase mode and the matching cap and adapter in normal mode. The original round fittings do not fit the newer flat covers.
  Flat-wall test 3MFFaceted shell 3MFCap + adapter 3MF
  The vase-mode STL inputs are solid outer shapes. The slicer creates their thin walls. Check that the sliced shell has no floor, roof, infill or supports. Keep the fittings in a separate normal-mode job.
4. 04

### Dry-fit, then assemble.

  Glue the track keys into the deck with the steep ends facing forward. Glue the waist column into the deck and torso. Insert each shoulder pin from outside the arm and glue only its innermost 5 mm into the torso. Keep glue out of the arm bearing. Glue the head peg into the torso with about 3.5 mm exposed, then lower the head onto it.
  For the faceted cover, seat the adapter's recessed underside around the head lip. Center the shell on its flat top with a broad panel facing forward, then fit the cap gently. Use small adhesive dots at the hidden shell-to-adapter joint. Keep the adapter free of the head so the cover lifts off. Test PETG-compatible adhesive on scrap first; it can haze a window.
  Keep the head and shoulder bearings free of glue. Handle the finished robot by its deck or torso.

Saved settings for the body and faceted cover

Settings embedded in the supplied baseline projects
Setting | Body | Faceted shell / test | Cap + adapter
Layer / first layer | 0.15 / 0.20 mm | 0.25 / 0.25 mm | 0.25 / 0.25 mm
Perimeters | 4 | 1 continuous spiral | 3
Infill | 20% gyroid | 0% | 100% rectilinear
Top / bottom layers | 5 / 5 | 0 / 0 | 4 / 3
Extrusion width | Project defaults | 0.60 mm | 0.45 mm
Brim | 3 mm | 4 mm | 4 mm
Supports | Off | Off | Off
Wall speed | 30 mm/s external | 15 mm/s | 15 mm/s
Nozzle / bed | Match your PLA profile | 250 / 85 °C | 250 / 85 °C
Fan range | Match your PLA profile | 0 to 15% | 30 to 50%

Use a print sheet suited to the material and temperatures within your spool's range. These are starting settings. Clear FDM prints still show layer lines, so test visibility with your filament before committing to a cover.

The optional five-color v2 project uses 2 perimeters, 10% grid infill and 6 top layers, plus different filament and speed settings. Its saved filament color labels differ from the intended body colors. Recheck the tool assignments and loaded spools. The table above describes the baseline project.

Use a clear-sheet window instead

If the printed test still distorts the face, print the hood and retainer, plus the shared cap and adapter. Cut one flat, untextured 0.50 mm clear PETG sheet panel. The sheet is a separate material, not a printed part.

1. Print the cutting template at 100% or Actual size. Disable Fit and Shrink, verify the 50 mm scale box, and test a paper cutout first.
2. Cut the trapezoid without heating or bending the sheet. It is 37.88 mm wide at the bottom, 25.20 mm at the top and 26.60 mm tall along its surface. Remove burrs.
3. With the cap off, place the sheet into the hood's rebate from the front. It does not slide down through the narrow top.
4. Bond the U-shaped retainer to the side ledges with tiny adhesive dots. Keep adhesive and protective film out of the viewing area.
5. Center and bond the hood to the adapter. Lower the shared cap gently onto the hood and sheet; reseat the sheet if the cap resists.

Hood + retainer 3MFCutting template PDFMetric outline SVG

Earlier dome versions and individual STL files

The original supported dome and the thinner curved vase cover are included so you can follow the revisions. The original dome uses internal supports; remove them through the bottom before assembly. The curved vase shell needs its own round cap and mounting ring, printed in normal mode.

Original dome 3MFCurved vase shell 3MFRound cap + ring 3MF

The complete ZIP contains individual body and cover STLs, color-separated meshes, all 3MF projects, the sheet template and a printing guide. No G-code is supplied. Slice the projects for your own printer.

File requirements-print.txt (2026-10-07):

numpy>=2.4,<3
trimesh==5.1.0
manifold3d>=3.5.3,<3.6
scipy>=1.17,<2
Pillow>=12.3,<13
networkx>=3.6,<4

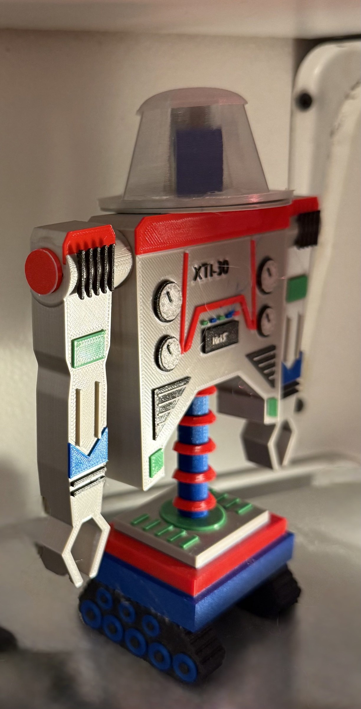
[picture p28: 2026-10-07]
docs/assets/printed-angle.jpg

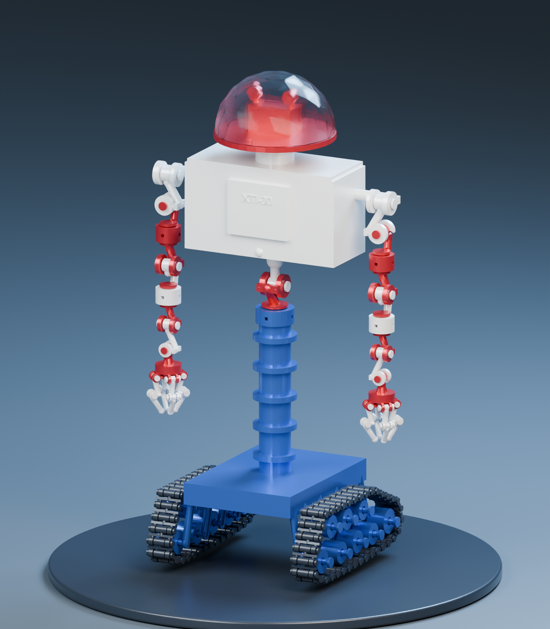
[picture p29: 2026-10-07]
renders/zoomer_print_in_place.png

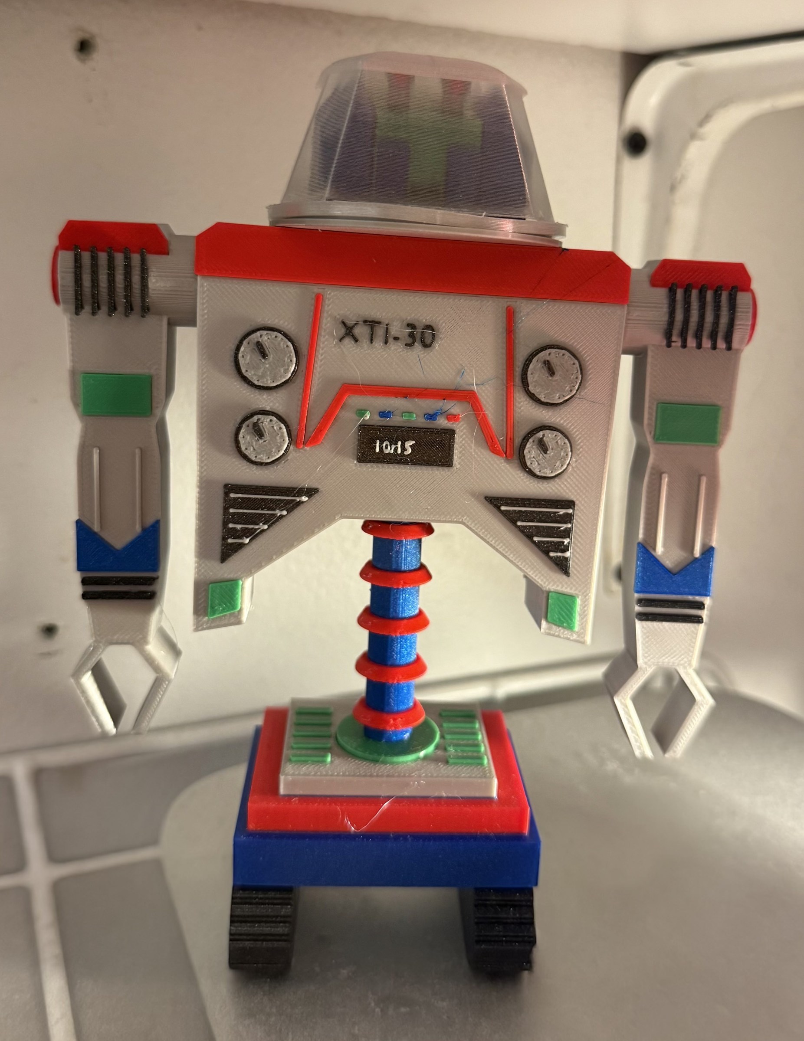
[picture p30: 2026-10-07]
docs/assets/printed-front.jpg

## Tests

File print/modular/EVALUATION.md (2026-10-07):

# Print revision assessment

The former captive assembly was a poor first print. It needed support below most of the arms, inside bearings, between tread links and inside a dome bonded to the head. Removing that support would load the smallest pins before the model had moved. A single failed axle or fused link could spoil a much larger assembly.

The revised model addresses those problems through part orientation and fewer joints. The main eleven parts now slice without support; the twelfth part is the optional dome, printed separately with accessible support. Printed 8 mm pins replace the fine captive axles. The column lies along the bed, and the track keys reach the bed in their side-down orientation. Head cheek bases also meet the platform, and the head socket closes with a sloped roof.

## Match to the drawing

The supplied drawing is a hand-drawn perspective view. It establishes the silhouette and front details, but it does not determine an exact depth or an engineering tolerance. The comparison uses manually selected image landmarks and aligns the robot heights. It does not report a pixel-similarity score.

| Proportion | Drawing estimate at 180 mm height | Revised model |
| --- | ---: | ---: |
| Overall width | About 140 mm | 140.6 mm |
| Chest height to lower wings | About 81 mm | 80 mm |
| Dome width | About 59 mm | 59 mm |
| Exposed central column | About 47 mm | 48 mm |

The revision restores the broad shoulders, tall chest with its lower cutout, four gauges, red center outline, clock, bellows details and long arms. The base-to-body spacing and hand height now follow the sketch. See [the comparison](qa/drawing_comparison.png) and [the front render](qa/front.png).

The model uses symmetry where the drawing is uneven. Its depth is inferred. The hands are sturdy fixed pincers, the belt and wheels form solid units, and blue covers the purple regions in the five-tool print. The dome reads differently in the orthographic front render because the drawing shows its rim as a perspective ellipse. The single view cannot establish a unique 3D reconstruction. These differences leave the robot recognizable while removing fragile details and trapped support.

## Iterations and evidence

The first geometry pass restored the proportions but revealed detached lettering, a corner contact between two chest details, and small export facets. Those were corrected in the source geometry and checked again after STL export. The first sliced revision revealed unsupported track keys and head details. The final revision extends those features to supporting geometry. It also adds a dome seating ledge and clearance around the locating lip.

The final check records 12 connected watertight parts, watertight color volumes, no neutral assembly intersections above the audit threshold, and no intersections in 99 sampled joint poses. PrusaSlicer 2.9.6 sliced all four supplied projects using the embedded XL5IS profile, 0.4 mm nozzles and 0.15 mm layers. The two main plates and coupons contain no support toolpaths; the dome contains support. None of the final slicing logs contains a support or stability warning.

The saved Blender file and renders use the exported print geometry. There are no substitute cosmetic shells or render-only bevels. The transparent dome material helps inspect the face but does not predict FDM clarity.

Printed tolerances, glue retention, layer strength, support removal, joint friction and wear still require physical checks. Start with the coupons, then inspect the first article. The files are ready for that test; they are not a physically qualified product.

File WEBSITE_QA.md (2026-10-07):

# Website export verification

Verified on October 6, 2026 against <https://zoomer3d.dgdg17291346462nk.chatgpt.site/>. The local source is `/Users/dgoldenh/Documents/GitHub/zoomer3D/website`, commit `b296b446e77055809638362b8dee912557438fc9`, published as version 9.

The live HTML matches that source apart from an injected Cloudflare hosting script. The export reuses the saved source, removes the original host's canonical and Open Graph URLs, and adds a `.nojekyll` marker. No visible copy, styles, application scripts, images, video or downloads changed. The 54 files other than `index.html` match the original SHA-256 hashes.

## Appearance

Full-page screenshots were compared at these viewport sizes. All nine sections had identical coordinates and heights, with no horizontal overflow or missing images.

| Viewport | Result |
| --- | --- |
| 1440 × 1000 | More than 99.99% of pixels match. Differences occur only in the native video's animated buffering indicator. |
| 768 × 1024 | More than 99.99% of pixels match. Differences occur only in the native video's animated buffering indicator. |
| 390 × 844 | Pixel-identical full-page screenshots. |
| 320 × 780 | Pixel-identical full-page screenshots. |

The recorded-example drawing editor screenshots are pixel-identical at 1440 and 390 pixels wide. The desktop hero and mobile editor were also visually inspected.

## Interactions and files

The same checks passed on the original and export at desktop and mobile widths:

- All eight ribbon links, sticky-header anchor clearance, and back/forward navigation.
- Image links opening in another tab and same-tab image navigation followed by Back.
- Opening and restoring all six visible expandable sections, including the default-open settings table.
- Loading the 19-stroke example, replaying strokes and cancelling replay with Undo.
- Four marker colors in order, keyboard drawing, pointer drawing, Undo and Clear.
- JSON export with the selected name and tolerance, reload persistence, and JSON import/export round trip.
- Error messages for malformed JSON and invalid target data, preserving the current drawing.
- Real mobile touch events creating a red stroke with two points.
- No JavaScript errors during the interaction checks.

The original and export both load the 202.12-second MP4 and expose native controls. Playback advanced on both. On the export's range-capable static preview, playback reached 39.36 seconds, paused, and sought to 199 seconds successfully. The preview returned HTTP 206 for a byte-range request. A simple Python HTTP server without byte-range support reset seeking to zero; the included preview script supports ranges.

All 56 public files returned HTTP 200 with matching SHA-256 hashes, including ZIP, MP4, BLEND, 3MF and PDF downloads. The validator checked two HTML pages, 114 local references and anchors, ZIP integrity, and agreement between the archived and public printing guide. Both JavaScript files passed syntax checks. The preview and validator passed Python syntax checks.

The Pages workflow uses the checkout, configure-pages, upload-pages-artifact and deploy-pages actions listed in [GitHub's workflow documentation](https://docs.github.com/en/pages/getting-started-with-github-pages/using-custom-workflows-with-github-pages). Its source directory is `docs/`, with a validation step before upload.

## Publication status

The intended repository is <https://github.com/dgoldenholz/zoomer3D>. GitHub Desktop created it and configured the local `origin` remote. The first published website commit is `e5c0b2b74abc4e59175d625dd8e54f2b12e7f88d`. Its remote `main` SHA matched the local commit before deployment.

GitHub Pages is enabled with GitHub Actions as its build source. The [deployment workflow](https://github.com/dgoldenholz/zoomer3D/actions/runs/37564146142) passed checkout, Pages configuration, website validation, artifact upload and deployment. The initial push run stopped at Pages configuration before Pages had been enabled.

The live URL is <https://dgoldenholz.github.io/zoomer3D/>. All 55 public website files returned HTTP 200 and matched the repository SHA-256 hashes, including HTML, CSS, JavaScript, images, example JSON, video and downloads. A request for video bytes 1000 through 1999 returned HTTP 206 and the exact expected bytes. The 54 original files other than `index.html` also retain their original hashes in the committed Git objects.

After copying the standalone site into this repository, the desktop and mobile interaction checks passed at widths of 1440 and 390 pixels. They covered navigation, back and forward, expandable sections, image links, the drawing editor, replay, import and export, draft persistence and real touch drawing. No JavaScript errors occurred.

The export needs no ChatGPT service. Google Fonts remains an external font dependency, matching the original. Browser drafts are scoped to each website origin and can be transferred through JSON export/import. MuJoCo training continues to run in the downloaded local simulator, as on the original site.

Browser logs, source/export screenshots and pixel comparisons are saved in the task workspace's `output/playwright/` directory. Transfer hashes, repository interaction checks, live HTTP results and deployment status are in `output/website-transfer/`. The standalone site is in `docs/`; the original nested source checkout in `website/` remains separate. The transfer added 63 files and preserved all 831 pre-existing project files. Git attributes gained binary rules scoped to `docs/`. A recoverable export copy remains in the task workspace's `zoomer3D-export/` directory.

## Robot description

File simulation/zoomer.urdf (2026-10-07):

<?xml version='1.0' encoding='utf-8'?>
<robot name="zoomer_xi30">
  <link name="base">
    <inertial>
      <origin xyz="0 0 0.025058005" />
      <mass value="0.36" />
      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
    </inertial>
    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
  </link>
  <link name="right_drive">
    <inertial>
      <origin xyz="0 0 0" />
      <mass value="0.006" />
      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
    </inertial>
    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
  </link>
  <joint name="right_drive" type="continuous">
    <parent link="base" />
    <child link="right_drive" />
    <origin xyz="-0.026908397 -0.025710798 -0.011228373" />
    <axis xyz="1 0 0" />
    <limit effort="0.063" velocity="4" />
    <dynamics damping=".002" friction="0" />
  </joint>
  <link name="right_idler_1">
    <inertial>
      <origin xyz="0 0 0" />
      <mass value="0.006" />
      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
    </inertial>
    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
  </link>
  <joint name="right_idler_1" type="continuous">
    <parent link="base" />
    <child link="right_idler_1" />
    <origin xyz="-0.026908397 -0.010537212 -0.011619755" />
    <axis xyz="1 0 0" />
    <limit effort="0.0" velocity="4" />
    <dynamics damping=".002" friction="0" />
  </joint>
  <link name="right_idler_2">
    <inertial>
      <origin xyz="0 0 0" />
      <mass value="0.006" />
      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
    </inertial>
    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
  </link>
  <joint name="right_idler_2" type="continuous">
    <parent link="base" />
    <child link="right_idler_2" />
    <origin xyz="-0.026908397 0.0021074424 -0.010641299" />
    <axis xyz="1 0 0" />
    <limit effort="0.0" velocity="4" />
    <dynamics damping=".002" friction="0" />
  </joint>
  <link name="right_idler_3">
    <inertial>
      <origin xyz="0 0 0" />
      <mass value="0.006" />
      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
    </inertial>
    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
  </link>
  <joint name="right_idler_3" type="continuous">
    <parent link="base" />
    <child link="right_idler_3" />
    <origin xyz="-0.026908397 0.014330609 -0.010641299" />
    <axis xyz="1 0 0" />
    <limit effort="0.0" velocity="4" />
    <dynamics damping=".002" friction="0" />
  </joint>
  <link name="right_idler_4">
    <inertial>
      <origin xyz="0 0 0" />
      <mass value="0.006" />
      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
    </inertial>
    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
  </link>
  <joint name="right_idler_4" type="continuous">
    <parent link="base" />
    <child link="right_idler_4" />
    <origin xyz="-0.026908397 0.026764519 -0.0088800795" />
    <axis xyz="1 0 0" />
    <limit effort="0.0" velocity="4" />
    <dynamics damping=".002" friction="0" />
  </joint>
  <link name="right_return_1">
    <inertial>
      <origin xyz="0 0 0" />
      <mass value="0.003" />
      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
    </inertial>
    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
  </link>
  <joint name="right_return_1" type="continuous">
    <parent link="base" />
    <child link="right_return_1" />
    <origin xyz="-0.026908397 -0.018334749 -7.3980776e-05" />
    <axis xyz="1 0 0" />
    <limit effort="0.0" velocity="4" />
    <dynamics damping=".002" friction="0" />
  </joint>
  <link name="right_return_2">
    <inertial>
      <origin xyz="0 0 0" />
      <mass value="0.003" />
      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
    </inertial>
    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
  </link>
  <joint name="right_return_2" type="continuous">
    <parent link="base" />
    <child link="right_return_2" />
    <origin xyz="-0.026908397 -0.0061115831 -0.00026967186" />
    <axis xyz="1 0 0" />
    <limit effort="0.0" velocity="4" />
    <dynamics damping=".002" friction="0" />
  </joint>
  <link name="right_return_3">
    <inertial>
      <origin xyz="0 0 0" />
      <mass value="0.003" />
      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
    </inertial>
    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
  </link>
  <joint name="right_return_3" type="continuous">
    <parent link="base" />
    <child link="right_return_3" />
    <origin xyz="-0.026908397 0.0065330716 0.00012171031" />
    <axis xyz="1 0 0" />
    <limit effort="0.0" velocity="4" />
    <dynamics damping=".002" friction="0" />
  </joint>
  <link name="left_drive">
    <inertial>
      <origin xyz="0 0 0" />
      <mass value="0.006" />
      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
    </inertial>
    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
  </link>
  <joint name="left_drive" type="continuous">
    <parent link="base" />
    <child link="left_drive" />
    <origin xyz="0.026908397 -0.025710798 -0.011228373" />
    <axis xyz="1 0 0" />
    <limit effort="0.063" velocity="4" />
    <dynamics damping=".002" friction="0" />
  </joint>
  <link name="left_idler_1">
    <inertial>
      <origin xyz="0 0 0" />
      <mass value="0.006" />
      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
    </inertial>
    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
  </link>
  <joint name="left_idler_1" type="continuous">
    <parent link="base" />
    <child link="left_idler_1" />
    <origin xyz="0.026908397 -0.010537212 -0.011619755" />
    <axis xyz="1 0 0" />
    <limit effort="0.0" velocity="4" />
    <dynamics damping=".002" friction="0" />
  </joint>
  <link name="left_idler_2">
    <inertial>
      <origin xyz="0 0 0" />
      <mass value="0.006" />
      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
    </inertial>
    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
  </link>
  <joint name="left_idler_2" type="continuous">
    <parent link="base" />
    <child link="left_idler_2" />
    <origin xyz="0.026908397 0.0021074424 -0.010641299" />
    <axis xyz="1 0 0" />
    <limit effort="0.0" velocity="4" />
    <dynamics damping=".002" friction="0" />
  </joint>
  <link name="left_idler_3">
    <inertial>
      <origin xyz="0 0 0" />
      <mass value="0.006" />
      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
    </inertial>
    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
  </link>
  <joint name="left_idler_3" type="continuous">
    <parent link="base" />
    <child link="left_idler_3" />
    <origin xyz="0.026908397 0.014330609 -0.010641299" />
    <axis xyz="1 0 0" />
    <limit effort="0.0" velocity="4" />
    <dynamics damping=".002" friction="0" />
  </joint>
  <link name="left_idler_4">
    <inertial>
      <origin xyz="0 0 0" />
      <mass value="0.006" />
      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
    </inertial>
    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
  </link>
  <joint name="left_idler_4" type="continuous">
    <parent link="base" />
    <child link="left_idler_4" />
    <origin xyz="0.026908397 0.026764519 -0.0088800795" />
    <axis xyz="1 0 0" />
    <limit effort="0.0" velocity="4" />
    <dynamics damping=".002" friction="0" />
  </joint>
  <link name="left_return_1">
    <inertial>
      <origin xyz="0 0 0" />
      <mass value="0.003" />
      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
    </inertial>
    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
  </link>
  <joint name="left_return_1" type="continuous">
    <parent link="base" />
    <child link="left_return_1" />
    <origin xyz="0.026908397 -0.018334749 -7.3980776e-05" />
    <axis xyz="1 0 0" />
    <limit effort="0.0" velocity="4" />
    <dynamics damping=".002" friction="0" />
  </joint>
  <link name="left_return_2">
    <inertial>
      <origin xyz="0 0 0" />
      <mass value="0.003" />
      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
    </inertial>
    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
  </link>
  <joint name="left_return_2" type="continuous">
    <parent link="base" />
    <child link="left_return_2" />
    <origin xyz="0.026908397 -0.0061115831 -0.00026967186" />
    <axis xyz="1 0 0" />
    <limit effort="0.0" velocity="4" />
    <dynamics damping=".002" friction="0" />
  </joint>
  <link name="left_return_3">
    <inertial>
      <origin xyz="0 0 0" />
      <mass value="0.003" />
      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
    </inertial>
    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
  </link>
  <joint name="left_return_3" type="continuous">
    <parent link="base" />
    <child link="left_return_3" />
    <origin xyz="0.026908397 0.0065330716 0.00012171031" />
    <axis xyz="1 0 0" />
    <limit effort="0.0" velocity="4" />
    <dynamics damping=".002" friction="0" />
  </joint>
  <link name="waist_yaw">
    <inertial>
      <origin xyz="0 0 0" />
      <mass value="0.0225" />
      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
    </inertial>
    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
  </link>
  <joint name="waist_yaw" type="continuous">
    <parent link="base" />
    <child link="waist_yaw" />
    <origin xyz="0 0 0.075174014" />
    <axis xyz="0 0 1" />
    <limit effort="0.23399999999999999" velocity="4" />
    <dynamics damping=".002" friction="0" />
  </joint>
  <link name="waist_pitch">
    <inertial>
      <origin xyz="0 0 0.027444481" />
      <mass value="0.135" />
      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
    </inertial>
    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
  </link>
  <joint name="waist_pitch" type="revolute">
    <parent link="waist_yaw" />
    <child link="waist_pitch" />
    <origin xyz="0 0 0.0053695724" />
    <axis xyz="1 0 0" />
    <limit effort="0.288" velocity="4" lower="-0.4363323129985824" upper="0.4363323129985824" />
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
